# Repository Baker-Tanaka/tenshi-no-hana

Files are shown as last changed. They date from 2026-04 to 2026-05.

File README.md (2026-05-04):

# Angel's Nose - ROS2 × Baker link. Dev × Rover

> ⚠️ This project is under active development. Features, wiring, and documentation may change.

**A whiskey barrel patrol rover that detects alcohol vapor, environmental conditions, and barrel liquid level.**

## Illustrative Image

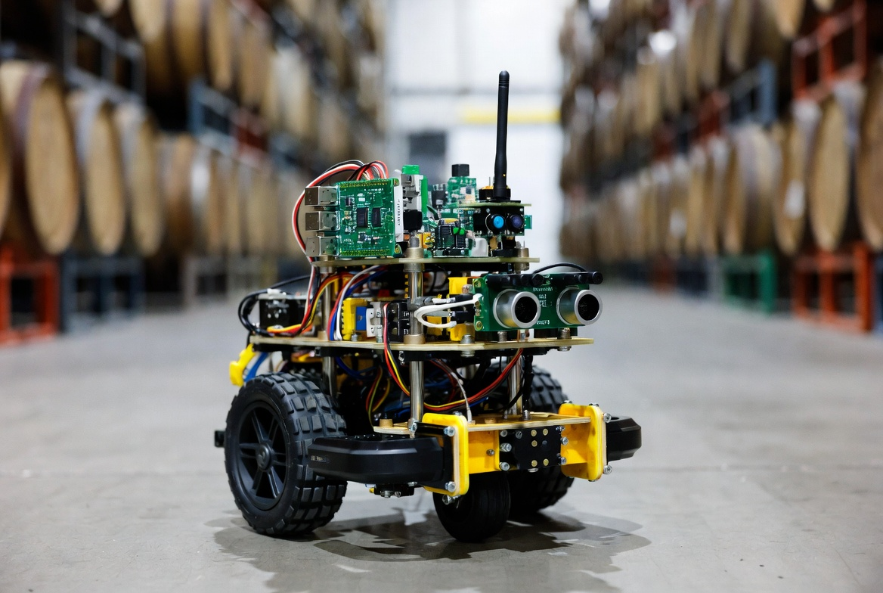
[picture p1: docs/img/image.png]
Project preview


System diagram

> 日本語版はこちら: [README.ja.md](./README.ja.md)

## Overview
Angel's Nose is a compact 2-wheel rover based on the Baker link. Dev(RP2040) board. It patrols distilleries and barrel aging warehouses, detects ethanol vapor, measures temperature, humidity, and pressure, and estimates barrel liquid surface using magnetic sensing.

This project combines:
- **Baker link. Dev (RP2040)**
- **XIAO-ESP32-C3 as a Wi-Fi ESP-hosted MCU**
- **Embassy-rs no_std async runtime**
- **micro_xrce_dds_rs** with a **micro-ROS Agent** bridge

## Key features
- Ethanol vapor detection as a proxy for the barrel's "angel's share"
- Environmental sensing with temperature, humidity, and pressure
- Non-contact barrel liquid level sensing using a floating magnet and magnetic field sensor
- Wi-Fi communication via XIAO-ESP32-C3
- Low-cost and lightweight no_std embedded design

## Hardware bill of materials
Estimated Japan-focused pricing as of April 2026.

| Part | Example | Approx. Price | Link | Notes |
| --- | --- | --- | --- | --- |
| 2WD robot chassis  | FT-DC-002 / 2WD Mini Smart Robot Mobile Platform Kit | ¥1,900 | [Akizuki](https://akizukidenshi.com/catalog/g/g113651/) | Includes motors; encoder-free version available |
| Baker link. Dev | - | ¥1,980 | [Switch Science](https://www.switch-science.com/products/10044) | Native Embassy-rs / Rust no_std support |
| Motor driver | DRV8835 dual motor driver | ¥400–1,395 | [Akizuki](https://akizukidenshi.com/catalog/g/g109848/) | Ideal for direct PWM motor control |
| Ethanol sensor | MQ-3B or MQ-3 module | ¥450 | [Akizuki](https://akizukidenshi.com/catalog/g/g116269/) | Main sensor for vapor detection; heater requires 5 V / 150 mA |
| Voltage divider | 10 kΩ + 15 kΩ resistors | < ¥10 | — | Required: scales MQ-3B AOUT (0–5 V) to 0–3 V for RP2040 ADC |
| Environment sensor | BME280 module (AE-BME280) | ¥1,650 | [Switch Science](https://www.switch-science.com/products/2236)  | Required for evaporation compensation |
| Optional IMU | 6-axis IMU module | ¥990 | [Switch Science](https://www.switch-science.com/products/8695)  | Useful for odometry and attitude estimation |
| Ultrasonic sensor  | - | ¥300 | [Switch Science](https://www.switch-science.com/products/8224/) | For obstacle avoidance |

```
GPIOs: CLK:6 MOSI:7 MISO:5 CS:10 HS:3 DR:4
```

## Wiring



> **MQ-3B wiring note**: The heater (VCC pin) requires a **5 V / 150 mA** external supply.
> AOUT can swing up to VCC (~5 V), which would damage the RP2040's 3.3 V ADC input.
> Add a **10 kΩ + 15 kΩ voltage divider** between AOUT and GP26 as shown in the schematic above.
> Allow ~2 minutes warm-up after power-on; the firmware suppresses publishing during this period.

## Wireless stack
- Uses **XIAO-ESP32-C3** with ESP-hosted MCU firmware
- Uses the `external/embassy` submodule and `embassy-net-esp-hosted` from the `upstream-esp-hosted-mcu` fork

## Software stack
- `micro_xrce_dds_rs` with micro-ROS Agent TCP transport
- Custom message support for `angel_nose_msgs` (ethanol level, liquid height, environment data)

## How it works
1. Position the rover at a fixed distance from the barrel. ArUco or AprilTag tracking is recommended.
2. Measure barrel liquid level with a floating cork and neodymium magnet using magnetic field sensing.
3. Use the MQ-3 sensor to "sniff" ambient ethanol vapor.

## Future work
- Autonomous mapping and multi-barrel patrol
- Estimating evaporation volume from liquid level data
- Web dashboard for distillery monitoring
- Full Rust no_std implementation across the stack

## ESP32-Hosted (ESP32-C3) pin mapping
Pin assignments are extracted from `sdkconfig`.

> Reference: [Seeed Studio XIAO ESP32C3 Getting Started](https://wiki.seeedstudio.com/XIAO_ESP32_C3_Getting_Started/)

### XIAO ESP32C3 GPIO ↔ physical pin mapping

| XIAO pin | GPIO | Default function | Notes |
| --- | --- | --- | --- |
| D0 | GPIO2  | ADC | ⚠️ Strapping pin |
| D1 | GPIO3  | ADC | |
| D2 | GPIO4  | ADC | MTMS (JTAG) |
| D3 | GPIO5  | ADC | MTDI (JTAG) |
| D4 | GPIO6  | SDA (I2C) | FSPICLK, MTCK (JTAG) |
| D5 | GPIO7  | SCL (I2C) | FSPID, MTDO (JTAG) |
| D6 | GPIO21 | UART TX | |
| D7 | GPIO20 | UART RX | |
| D8 | GPIO8  | SPI SCK | ⚠️ Strapping pin |
| D9 | GPIO9  | SPI MISO | ⚠️ Strapping pin / BOOT button |
| D10 | GPIO10 | SPI MOSI | FSPICS0 |

### Recommended esp-hosted slave wiring

> Avoid all strapping pins (GPIO2/8/9) for stable operation.

| Signal | GPIO | XIAO pin | Purpose |
| --- | --- | --- | --- |
| SPI MOSI | GPIO7  | D5 | Required |
| SPI MISO | GPIO5  | D3 | Required |
| SPI CLK | GPIO6  | D4 | Required |
| SPI CS | GPIO10 | D10 | Required |
| Handshake  | GPIO3  | D1 | Timing sync |
| Data Ready | GPIO4  | D2 | Data arrival notification |
| Reset | GPIO21 | D6 | Recommended |

#### Changes from previous wiring

| Signal | Old GPIO | New GPIO | Reason |
| --- | --- | --- | --- |
| SPI MISO | GPIO2 (D0) | GPIO5 (D3)  | Avoid strapping pin and boot instability |
| Reset | none | GPIO21 (D6) | Add host reset control |

#### Spare pins

| XIAO pin | GPIO | Notes |
| --- | --- | --- |
| D0 | GPIO2  | Spare, but avoid strapping pin |
| D7 | GPIO20 | Spare UART RX for debugging |
| D8 | GPIO8  | Spare, but avoid strapping pin |
| D9 | GPIO9  | Spare, but avoid BOOT button pin |

### ESP-IDF menuconfig setup

```powershell
idf.py menuconfig
```

Navigate to **Example Configuration → Bus Config → SPI Full-Duplex Configuration** and set:

| Option | Value |
| --- | ----- |
| SPI MOSI (GPIO) | 7 |
| SPI MISO (GPIO) | 5 |
| SPI CLK (GPIO) | 6 |
| SPI CS (GPIO) | 10 |
| Handshake (GPIO)  | 3 |
| Data Ready (GPIO) | 4 |
| Reset pin (GPIO)  | 21 |

Save and rebuild.

```bash
# Create esp-hosted-mcu slave sample (ESP-IDF v5.3+ assumed)
idf.py create-project-from-example "espressif/esp_hosted:slave"
cd slave
idf.py set-target esp32c3
idf.py menuconfig
# Set SPI Full-Duplex Configuration:
#   MISO=5, MOSI=7, CLK=6, CS=10, HS=3, DR=4
#   Reset GPIO=21
idf.py build flash
```

## Submodule setup

RP2040-side dependencies are managed via git submodules:

```bash
git submodule update --init --recursive external/embassy external/micro_xrce_dds_rs
```

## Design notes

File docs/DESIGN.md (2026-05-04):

# 天使の鼻 — 設計書 (DESIGN.md)

> **プロジェクト名**: 天使の鼻 (Angel's Nose)
> **最終更新**: 2026-04-19

---

## 1. プロジェクト概要

ウィスキー蒸留所・熟成庫内を自律巡回する 2WD ローバー。
空気中のエタノール蒸気（天使の分け前）、温湿度・気圧、樽内液面を計測し、
ROS2 経由でリアルタイム監視する。

**コアスタック**: Baker link. Dev (RP2040) + Embassy-rs (Rust no\_std) + micro_xrce_dds_rs / micro-ROS Agent

---

## 2. システムアーキテクチャ

```text
┌───────────────────────────────────────────────────────────┐
│                Baker link. Dev (RP2040)                    │
│                   SPI Master                              │
│                                                           │
│  ┌──────────┐  ┌──────────┐  ┌──────────┐  ┌──────────┐ │
│  │ MQ-3     │  │ BME280   │  │ DRV8835  │  │ HC-SR04  │ │
│  │ (ADC)    │  │ (I2C)    │  │ (PWM)    │  │ (GPIO)   │ │
│  │ GP26     │  │ GP4/GP5  │  │ GP10-11  │  │ GP2/GP3  │ │
│  └──────────┘  └──────────┘  └──────────┘  └──────────┘ │
│                                                           │
│  ┌──────────────────────────────────────────────────────┐ │
│  │  SPI0 (GP16-19) + Control (GP13-15)                  │ │
│  │  embassy-net-esp-hosted                               │ │
│  └──────────────────┬───────────────────────────────────┘ │
└─────────────────────┼─────────────────────────────────────┘
                      │ SPI Full-Duplex
                      │ + Handshake / Data Ready / Reset
┌─────────────────────┼─────────────────────────────────────┐
│  XIAO ESP32-C3      │                                     │
│  esp-hosted-mcu     ▼                                     │
│  (SPI Slave)  ── WiFi ──► AP                              │
└───────────────────────────────────────────────────────────┘
                      │
                      │ TCP/IP (WiFi)
                      ▼
┌───────────────────────────────────────────────────────────┐
│  Host PC / Docker                                         │
│                                                           │
│  ┌──────────────┐  ┌────────────────┐  ┌──────────────┐  │
│  │ micro-ROS    │  │ ROS2 Node      │  │ Web          │  │
│  │ Agent :8888  │  │ rmw_fastrtps_cpp │  │ Dashboard    │  │
│  └──────────────┘  └────────────────┘  └──────────────┘  │
└───────────────────────────────────────────────────────────┘
```

---

## 3. ソフトウェアレイヤー

```text
┌─────────────────────────────────────────────────────┐
│  Application (examples/wifi_microros_sensors.rs)    │
│  Publisher<StringMsg> / Subscription<StringMsg>     │
├─────────────────────────────────────────────────────┤
│  micro_xrce_dds_rs   (external/micro_xrce_dds_rs)   │
│  ┌─────────────────────────────────────────────┐    │
│  │  sdk/  — NodeBuilder, Node, spin()          │    │
│  │  ros2/ — TopicKeyExpr, Publisher, Sub, QoS  │    │
│  │  session/ — Session, Reconnect              │    │
│  │  transport/ — XRCE-DDS, TCP, fragmentation   │    │
│  │  cdr/  — CDR LE serialization               │    │
│  └─────────────────────────────────────────────┘    │
├─────────────────────────────────────────────────────┤
│  embassy-net  (TCP/IP stack)                        │
│  └── TcpSocket  — Read + Write → NodeBuilder       │
├─────────────────────────────────────────────────────┤
│  embassy-net-esp-hosted  (WiFi over SPI)            │
│  └── EspHosted → NetDevice                          │
├─────────────────────────────────────────────────────┤
│  embassy-rp  (RP2040 HAL)                           │
│  └── SPI0 (async) + GPIO (Handshake/DR/Reset)       │
├─────────────────────────────────────────────────────┤
│  Hardware: Baker link. Dev ↔ XIAO ESP32-C3 (SPI)    │
└─────────────────────────────────────────────────────┘
```

---

## 4. ハードウェア構成

### 4.1 BOM 要約

| 部品 | 品番 | 価格目安 | 役割 |
| --- | --- | --- | --- |
| 2WD シャーシ | FT-DC-002 | ¥1,900 | 車体 |
| Baker link. Dev | RP2040 | ¥1,980 | メインMCU |
| XIAO ESP32-C3 | Seeed Studio | ¥800 | WiFi コプロセッサ (esp-hosted) |
| DRV8835 | デュアルモータードライバ | ¥400 | モーター制御 |
| MQ-3B | エタノールセンサー | ¥450 | 天使の分け前検知 |
| BME280 | AE-BME280 モジュール | ¥1,080 | 温湿度・気圧 |
| HC-SR04 | 超音波センサー | ¥300 | 障害物回避 |

### 4.2 RP2040 (Baker link. Dev) ↔ XIAO ESP32-C3 SPI 接続

> WIZ630io と同一 SPI0 バスレイアウト (GP14-19) を再利用

| RP2040 GPIO | ESP32-C3 GPIO | XIAO Pin | 信号名 | 用途 |
| --- | --- | --- | --- | --- |
| GP16 (SPI0 RX)  | GPIO5 | D3 | SPI MISO | データ入力 |
| GP17 (GPIO out) | GPIO10 | D10 | SPI CS | チップセレクト |
| GP18 (SPI0 SCK) | GPIO6 | D4 | SPI CLK | クロック |
| GP19 (SPI0 TX)  | GPIO7 | D5 | SPI MOSI | データ出力 |
| GP15 (GPIO in)  | GPIO3 | D1 | Handshake  | タイミング同期 |
| GP13 (GPIO in)  | GPIO4 | D2 | Data Ready | データ到着通知 |
| GP14 (GPIO out) | GPIO21 | D6 | Reset | リセット制御 |
| 3V3 OUT | 3V3 | — | 電源 | 3.3V 給電 |
| GND | GND | — | GND | グランド |

### 4.3 RP2040 その他ピンアサイン

| RP2040 GPIO | 機能 | 接続先 |
| --- | --- | --- |
| GP4 (I2C0 SDA) | I2C データ | BME280 SDA |
| GP5 (I2C0 SCL) | I2C クロック | BME280 SCL |
| GP26 (ADC0) | ADC 入力 | MQ-3B アナログ出力 |
| GP10 | PWM (左モーター) | DRV8835 AIN1 |
| GP11 | PWM (右モーター) | DRV8835 BIN1 |
| GP2 | GPIO (Trigger) | HC-SR04 Trig |
| GP3 | GPIO (Echo) | HC-SR04 Echo |
| GP20 | LED (赤) | ステータス LED |
| GP21 | LED (橙) | ステータス LED |
| GP22 | LED (緑) | ステータス LED |

### 4.4 注意事項

1. **ESP32-C3 の I2C ピン (D4/D5) は SPI で占有** — I2C センサーはすべて RP2040 側に接続
2. **ESP32-C3 の JTAG デバッグ不可** — GPIO4〜7 が SPI + 信号線で使用済み。USB シリアルでデバッグ
3. **GPIO9 (BOOT ボタン) は Data Ready に使用不可** — GPIO4 (D2) に変更済み
4. **ストラッピングピン (GPIO2/8/9) は未使用**

---

## 5. ESP32-C3 esp-hosted-mcu スレーブ準備

ESP32-C3 は **esp-hosted-mcu** ファームウェアを書き込み、SPI スレーブとして動作させる。
RP2040 から `embassy-net-esp-hosted` 経由で WiFi 接続を利用する。

### 5.1 ファームウェアビルド手順

```sh
# esp-hosted-mcu リポジトリをクローン
git clone --recursive https://github.com/espressif/esp-hosted-mcu.git
cd esp-hosted-mcu

# ESP-IDF 環境セットアップ
. ./esp-idf/export.sh

# ターゲットを ESP32-C3 に設定
idf.py set-target esp32c3

# ピン設定のカスタマイズ
idf.py menuconfig
```

### 5.2 menuconfig 設定

**Example Configuration → Bus Config → SPI Full-Duplex Configuration:**

| 設定項目 | 値 |
| --- | --- |
| SPI MOSI (GPIO) | **7**  |
| SPI MISO (GPIO) | **5**  |
| SPI CLK (GPIO) | **6**  |
| SPI CS (GPIO) | **10** |
| Handshake (GPIO)  | **3**  |
| Data Ready (GPIO) | **4**  |
| Reset pin (GPIO)  | **21** |

### 5.3 ビルド・フラッシュ

```sh
# ビルド
idf.py build

# XIAO ESP32-C3 を BOOT モードで USB 接続
# (BOOT ボタンを押しながら USB 接続、または BOOT + RESET)
idf.py -p /dev/ttyACM0 flash

# ログ確認 (オプション)
idf.py -p /dev/ttyACM0 monitor
```

フラッシュ後、ESP32-C3 は SPI スレーブとして起動し、RP2040 からの SPI コマンドを待機する。

---

## 6. 開発ロードマップ

### Phase 1: WiFi 通信（最優先）

ESP32-C3 (esp-hosted) 経由で micro-ROS Agent に TCP 接続し、ROS2 トピックを pub/sub する。

| ステップ | 内容 | 成果物 |
| --- | --- | --- |
| 1-1 | ESP32-C3 に esp-hosted-mcu ファームウェア書き込み | ESP32-C3 SPI スレーブ起動 |
| 1-2 | Cargo.toml に WiFi 依存追加 | `wifi` feature flag |
| 1-3 | WiFi 通信サンプル作成 | `examples/wifi_microros_sensors.rs` |
| 1-4 | 動作確認 (Docker + verify_sub.py) | `/chatter` メッセージ受信 |

**検証基準**:
- `cargo build --no-default-features --features wifi --example wifi_microros_sensors` 成功
- RTT ログ: DHCP 取得 → TCP 接続 → micro-ROS XRCE-DDS セッション成功
- `verify_sub.py` で `/chatter` メッセージ受信

### Phase 2: センサー統合

BME280 (I2C) と MQ-3B (ADC) のセンサーデータを取得し、ROS2 トピックとしてパブリッシュする。

| ステップ | 内容 | 成果物 | 状態 |
| --- | --- | --- | ---- |
| 2-1 | BME280 I2C ドライバ統合 | `bme280` crate (sync/blocking I2C)  | ✅ |
| 2-2 | MQ-3 ADC 読み取り | embassy-rp ADC (GP26) | ✅ |
| 2-3 | スタンドアロンセンサー読み取り | `examples/sensor_read.rs` | ✅ |
| 2-4 | センサーデータ ROS2 パブリッシュ | `examples/wifi_microros_sensors.rs` | ✅ |

**ROS2 トピック**:

| トピック | 型 | 内容 |
| --- | --- | --- |
| `/angel_nose/temperature` | `std_msgs/Float32` | BME280 温度 [°C]  |
| `/angel_nose/humidity` | `std_msgs/Float32` | BME280 湿度 [%] |
| `/angel_nose/pressure` | `std_msgs/Float32` | BME280 気圧 [hPa] |
| `/angel_nose/ethanol` | `std_msgs/Float32` | MQ-3B 電圧 [V] |

**ビルドコマンド**:
```sh
# センサー単体テスト
cargo build --no-default-features --features sensor --example sensor_read

# WiFi + センサー + micro-ROS パブリッシュ
cargo build --no-default-features --features wifi,sensor --example wifi_microros_sensors
```

**検証基準**:
- `cargo check --features sensor --example sensor_read` 成功
- `cargo check --features wifi,sensor --example wifi_microros_sensors` 成功
- RTT ログ: BME280 温湿度気圧 + MQ-3B ADC 値の周期的出力
- ROS2 側: `ros2 topic echo /angel_nose/temperature std_msgs/msg/Float32` でデータ受信

### Phase 3: モーター制御

| ステップ | 内容 | 成果物 |
| --- | --- | --- |
| 3-1 | DRV8835 PWM 制御 | 2WD 前後進・旋回 |
| 3-2 | `/cmd_vel` サブスクライブ | Twist → モーター PWM 変換 |

### Phase 4: 障害物回避・ナビゲーション

| ステップ | 内容 | 成果物 |
| --- | --- | --- |
| 4-1 | HC-SR04 超音波測距 | 前方障害物距離 |
| 4-2 | IMU (6 軸) odom 計算 | 姿勢推定 |
| 4-3 | 簡易障害物回避ロジック | 自律走行 |

### Phase 5: 統合・自律巡回

| ステップ | 内容 | 成果物 |
| --- | --- | --- |
| 5-1 | 複数樽巡回マッピング | ArUco/AprilTag 位置推定 |
| 5-2 | 液面磁界測定 | 浮遊ネオジム磁石 + ホールセンサー |
| 5-3 | 天使の分け前蒸発量推定 | エタノール + 液面データ統合 |
| 5-4 | Web ダッシュボード | ROS2 → WebSocket → ブラウザ |

---

## 7. WiFi 通信の実装パターン

`examples/wifi_microros_sensors.rs` をテンプレートとし、`embassy-net-wiznet` を `embassy-net-esp-hosted` に置換する。

### 7.1 タスク構成

```text
main()
  ├── esp_hosted_task  — SPI 通信ドライバループ
  ├── net_task         — embassy-net パケット I/O ループ
  ├── microros_task    — DHCP → TCP → XRCE-DDS / micro-ROS → Node::spin()
  └── app_task         — Publisher.send() / Subscription.try_recv()
```

### 7.2 トランスポート抽象化

micro_xrce_dds_rs の `XrceSession::connect()` は `T: Read + Write` を受け取る。
TCP ソケットをそのまま渡せるため、WiFi/Ethernet の違いはネットワークデバイス層のみ。

```rust
let mut socket = TcpSocket::new(stack, &mut rx, &mut tx);
socket.connect(agent_endpoint).await?;
let session = XrceSession::connect(socket, SESSION_ID, CLIENT_KEY).await?;
```

---

## 8. ビルド・デプロイ

### 8.1 開発環境

- **Dev Container**: Rust 1.94.1 + thumbv6m-none-eabi
- **デバッガ**: probe-rs (Baker link. Dev 内蔵 CMSIS-DAP)
- **ROS2**: Docker (micro-ROS Agent)

### 8.2 ビルドコマンド

```sh
# 通常ビルド (HAL + defmt)
cargo build --release

# Embassy サンプル
cargo build --no-default-features --features embassy --example embassy_blinky

# WiFi サンプル (Phase 1)
cargo build --no-default-features --features wifi --example wifi_microros_sensors

# 書き込み (probe-rs)
cargo run --release

# UF2 変換 (USB ブートローダ書き込み用)
elf2uf2-rs target/thumbv6m-none-eabi/release/tenshi-no-hana target/tenshi-no-hana.uf2
```

### 8.3 Docker (micro-ROS Agent)

```sh
cd <project_root>
docker compose up -d

# 動作確認
python3 verify_sub.py

# または ROS2 CLI
ros2 topic echo /chatter std_msgs/msg/String
```

---

## 9. 関連リンク

- [Baker link. Dev](https://www.baker-link.com/)
- [embassy-net-esp-hosted](https://github.com/embassy-rs/embassy/tree/embassy-net-esp-hosted-v0.3.0/embassy-net-esp-hosted)
- [esp-hosted-mcu](https://github.com/espressif/esp-hosted-mcu)
- [Seeed Studio XIAO ESP32C3](https://wiki.seeedstudio.com/XIAO_ESP32C3_Getting_Started/)

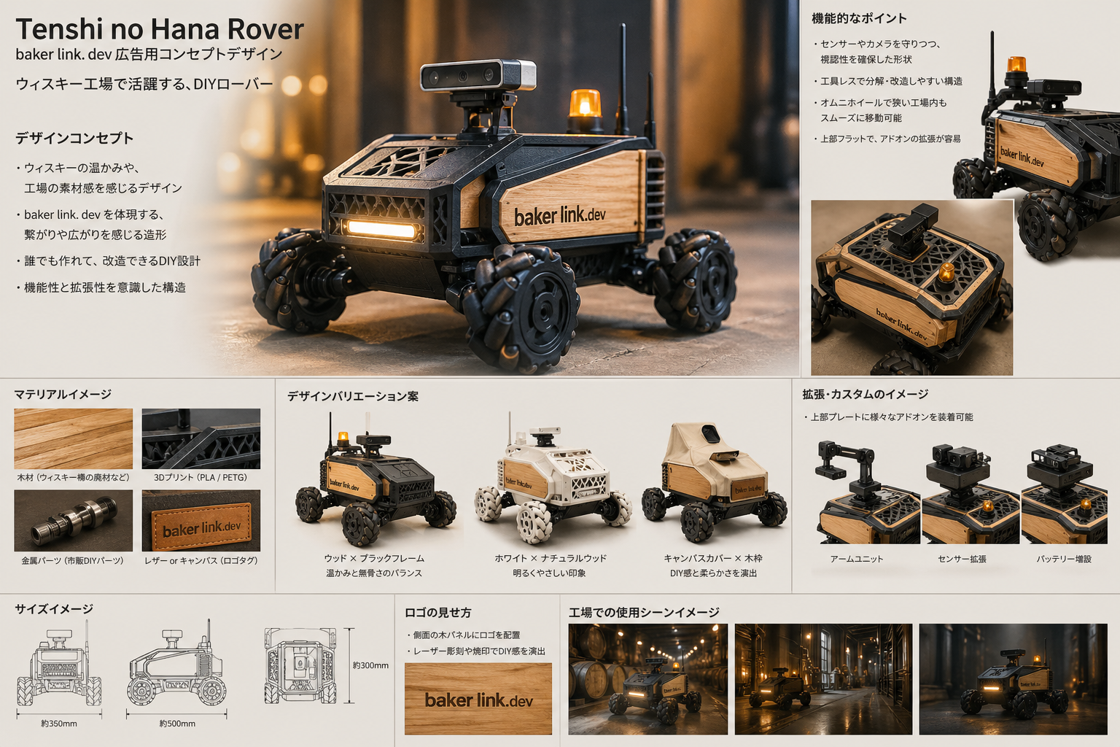
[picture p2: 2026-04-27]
docs/img/tenshinohana_concept.png

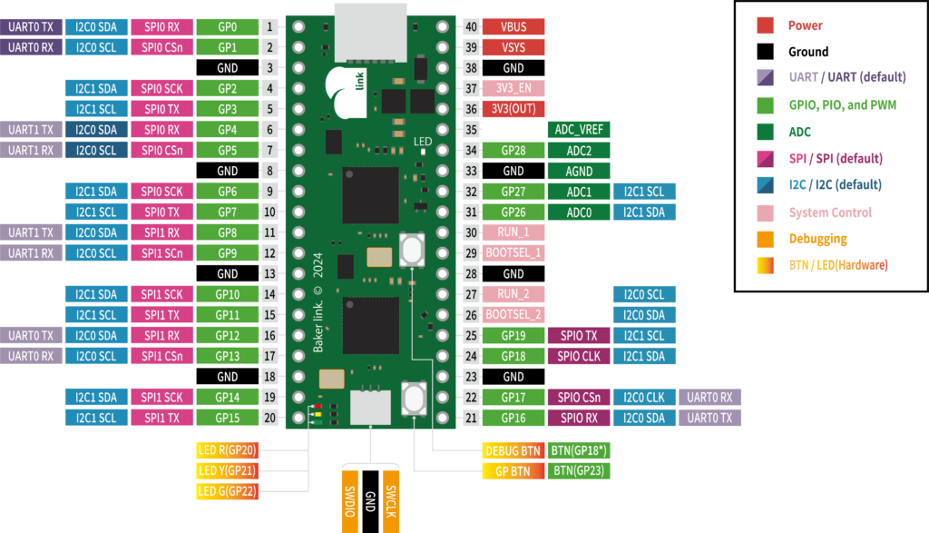
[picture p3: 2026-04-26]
docs/schematics/bld_image.png

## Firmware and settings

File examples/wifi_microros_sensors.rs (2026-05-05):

// wifi_microros_sensors.rs — RP2040 → WiFi → micro-ROS Agent → ROS2 sensor topics.
//
// Published topics:
//   /angel_nose/temperature  std_msgs/Float32   BME280 [°C]
//   /angel_nose/humidity     std_msgs/Float32   BME280 [%]
//   /angel_nose/pressure     std_msgs/Float32   BME280 [hPa]
//   /angel_nose/ethanol      std_msgs/Float32   MQ-3B AOUT [V]
//   /angel_nose/range        sensor_msgs/Range  HC-SR04 [m]
//   /angel_nose/imu          sensor_msgs/Imu    ICM-20602 6-axis
//
// Architecture (v0.2):
//   main()       — hardware init, WiFi, TCP, Runtime::start, spawn tasks
//   xrce_exec    — Executor task (sole TCP socket owner)
//   sensor_node  — reads all sensors AND publishes directly (no inter-task channels)
//
// Build:
//   cargo build --release --no-default-features --features wifi,sensor --example wifi_microros_sensors
#![no_std]
#![no_main]

#[path = "../src/wifi_config.rs"]
mod wifi_config;

use bme280::i2c::BME280;
use core::cell::RefCell;
use cortex_m_rt::exception;
use defmt::*;
use defmt_rtt as _;
use embassy_executor::Spawner;
use embassy_net::tcp::TcpSocket;
use embassy_net::{DhcpConfig, Runner as NetRunner, Stack, StackResources};
use embassy_net_esp_hosted_mcu::{
    self, BufferType, EspConfig, NetDriver, Runner as EspRunner, SpiInterface, State,
    MAX_SPI_BUFFER_SIZE,
};
use embassy_rp::adc::{
    Adc, Channel as AdcChannel, Config as AdcConfig, InterruptHandler as AdcIrqHandler,
};
use embassy_rp::gpio::{Input, Level, Output, Pull};
use embassy_rp::i2c::{Blocking as I2cBlocking, Config as I2cConfig, I2c};
use embassy_rp::spi::{Async as SpiAsync, Config as SpiConfig, Phase, Polarity, Spi};
use embassy_rp::{bind_interrupts, dma, peripherals::*};
use embassy_time::{with_timeout, Delay, Duration, Instant, Timer};
use embedded_hal::i2c::I2c as I2cTrait;
use embedded_hal_bus::i2c::RefCellDevice;
use embedded_hal_bus::spi::ExclusiveDevice;
use micro_xrce_dds_rs::{client_key, msg, Context, Executor, Runtime, RuntimeConfig};
use panic_probe as _;
use static_cell::StaticCell;
use wifi_config::AppConfig;

#[exception]
unsafe fn HardFault(_ef: &cortex_m_rt::ExceptionFrame) -> ! {
    defmt::panic!("HardFault: possible stack overflow or bus fault");
}

bind_interrupts!(struct Irqs {
    DMA_IRQ_0    => dma::InterruptHandler<DMA_CH0>, dma::InterruptHandler<DMA_CH1>;
    ADC_IRQ_FIFO => AdcIrqHandler;
});

const SAMPLE_PERIOD_MS: u64 = 1_000;
const MQ3B_WARMUP_SAMPLES: u32 = (6_000 / SAMPLE_PERIOD_MS) as u32;

type MySpi = Spi<'static, SPI0, SpiAsync>;
type MySpiDevice = ExclusiveDevice<MySpi, Output<'static>, Delay>;
type MySpiIface = SpiInterface<MySpiDevice, Input<'static>>;
type MyEspRunner = EspRunner<'static, MySpiIface, Output<'static>>;
type MyI2cBus = RefCell<I2c<'static, I2C0, I2cBlocking>>;
type MyI2cDev = RefCellDevice<'static, I2c<'static, I2C0, I2cBlocking>>;
type MyBme280 = BME280<MyI2cDev>;
type MyExecutor = Executor<TcpSocket<'static>>;

static ESP_STATE: StaticCell<State> = StaticCell::new();
static STACK_RESOURCES: StaticCell<StackResources<4>> = StaticCell::new();
static I2C_BUS: StaticCell<MyI2cBus> = StaticCell::new();
static RUNTIME: Runtime = Runtime::new();

#[embassy_executor::main]
async fn main(spawner: Spawner) {
    let p = embassy_rp::init(Default::default());
    Timer::after(Duration::from_millis(500)).await;
    info!("[main] start");

    // SPI0 → ESP32-C3 (Mode 3)
    let mut spi_cfg = SpiConfig::default();
    spi_cfg.frequency = 10_000_000;
    spi_cfg.polarity = Polarity::IdleHigh;
    spi_cfg.phase = Phase::CaptureOnSecondTransition;
    let spi = Spi::new(
        p.SPI0, p.PIN_18, p.PIN_19, p.PIN_16, p.DMA_CH0, p.DMA_CH1, Irqs, spi_cfg,
    );
    let cs = Output::new(p.PIN_17, Level::High);
    let handshake = Input::new(p.PIN_15, Pull::Down);
    let data_ready = Input::new(p.PIN_13, Pull::Down);
    let reset = Output::new(p.PIN_14, Level::Low);

    let spi_dev = ExclusiveDevice::new(spi, cs, Delay).unwrap();
    let spi_iface = SpiInterface::new(spi_dev, handshake, data_ready);
    let esp_state = ESP_STATE.init(State::new());
    let (net_device, mut control, esp_runner) =
        embassy_net_esp_hosted_mcu::new(esp_state, spi_iface, reset, None).await;
    spawner.spawn(esp_hosted_task(esp_runner).unwrap());

    let cfg = AppConfig::new();
    info!("[wifi] connecting to \"{}\"...", cfg.wifi_ssid);
    defmt::unwrap!(
        control
            .init(EspConfig {
                static_rx_buf_num: 10,
                dynamic_rx_buf_num: 32,
                tx_buf_type: BufferType::Dynamic,
                static_tx_buf_num: 0,
                dynamic_tx_buf_num: 32,
                rx_mgmt_buf_type: BufferType::Dynamic,
                rx_mgmt_buf_num: 20,
            })
            .await
    );
    let connected = defmt::unwrap!(control.connect(cfg.wifi_ssid, cfg.wifi_password).await);
    defmt::assert!(connected, "WiFi association failed");
    info!("[wifi] connected");

    let (stack, net_runner) = embassy_net::new(
        net_device,
        embassy_net::Config::dhcpv4(DhcpConfig::default()),
        STACK_RESOURCES.init(StackResources::new()),
        0x1234_5678_9abc_def0u64,
    );

    // I2C0: BME280 @ 0x76, ICM-20602 @ 0x68
    let raw_i2c = I2c::new_blocking(p.I2C0, p.PIN_5, p.PIN_4, I2cConfig::default());
    let i2c_bus = I2C_BUS.init(RefCell::new(raw_i2c));

    let bme_dev = RefCellDevice::new(i2c_bus);
    let mut bme280: MyBme280 = BME280::new_primary(bme_dev);
    match bme280.init(&mut Delay) {
        Ok(()) => info!("[bme280] initialized"),
        Err(_) => error!("[bme280] init failed — check wiring"),
    }
    {
        let mut imu_tmp = RefCellDevice::new(i2c_bus);
        match icm20602_init(&mut imu_tmp).await {
            Ok(()) => info!("[imu] ICM-20602 ready"),
            Err(()) => error!("[imu] ICM-20602 init failed"),
        }
    }
    let imu_dev = RefCellDevice::new(i2c_bus);

    let adc = Adc::new(p.ADC, Irqs, AdcConfig::default());
    let mq3_ch = AdcChannel::new_pin(p.PIN_26, Pull::None);
    let trig = Output::new(p.PIN_2, Level::Low);
    let echo = Input::new(p.PIN_3, Pull::None);

    spawner.spawn(net_task(net_runner).unwrap());

    // Wait for DHCP.
    while stack.config_v4().is_none() {
        Timer::after(Duration::from_millis(500)).await;
    }
    info!("[microros] DHCP OK");

    static TCP_RX: StaticCell<[u8; 4096]> = StaticCell::new();
    static TCP_TX: StaticCell<[u8; 4096]> = StaticCell::new();
    let tcp_rx = TCP_RX.init([0u8; 4096]);
    let tcp_tx = TCP_TX.init([0u8; 4096]);

    let agent_ep = cfg.agent_endpoint();
    let mut socket = TcpSocket::new(stack, tcp_rx, tcp_tx);
    socket.set_timeout(Some(Duration::from_secs(30)));
    if with_timeout(Duration::from_secs(10), socket.connect(agent_ep))
        .await
        .map(|r| r.is_ok())
        .unwrap_or(false)
    {
        info!("[microros] TCP connected");
    } else {
        defmt::panic!("[microros] TCP connect timeout");
    }

    let (ctx, exec) = defmt::unwrap!(
        RUNTIME
            .start(socket, RuntimeConfig::new(0x81, client_key!()))
            .await
    );
    info!("[microros] runtime started");

    spawner.spawn(xrce_exec(exec).unwrap());
    spawner
        .spawn(sensor_node(ctx, bme280, adc, mq3_ch, trig, echo, imu_dev))
        .unwrap();
}

#[embassy_executor::task]
async fn esp_hosted_task(runner: MyEspRunner) {
    static TX_BUF: StaticCell<[u8; MAX_SPI_BUFFER_SIZE]> = StaticCell::new();
    static RX_BUF: StaticCell<[u8; MAX_SPI_BUFFER_SIZE]> = StaticCell::new();
    runner
        .run(
            TX_BUF.init([0u8; MAX_SPI_BUFFER_SIZE]),
            RX_BUF.init([0u8; MAX_SPI_BUFFER_SIZE]),
        )
        .await
}

#[embassy_executor::task]
async fn net_task(mut runner: NetRunner<'static, NetDriver<'static>>) {
    runner.run().await
}

#[embassy_executor::task]
async fn xrce_exec(exec: MyExecutor) -> ! {
    exec.run().await
}

/// Reads all sensors and publishes to micro-ROS — no inter-task channels needed.
#[embassy_executor::task]
async fn sensor_node(
    ctx: Context,
    mut bme280: MyBme280,
    mut adc: Adc<'static, embassy_rp::adc::Async>,
    mut mq3_ch: AdcChannel<'static>,
    mut trig: Output<'static>,
    mut echo: Input<'static>,
    mut imu_dev: MyI2cDev,
) -> ! {
    let node = defmt::unwrap!(ctx.create_node("tenshi_no_hana").await);
    let pub_temp = defmt::unwrap!(
        node.create_publisher::<msg::std_msgs::Float32>("/angel_nose/temperature")
            .await
    );
    let pub_humi = defmt::unwrap!(
        node.create_publisher::<msg::std_msgs::Float32>("/angel_nose/humidity")
            .await
    );
    let pub_pres = defmt::unwrap!(
        node.create_publisher::<msg::std_msgs::Float32>("/angel_nose/pressure")
            .await
    );
    let pub_etoh = defmt::unwrap!(
        node.create_publisher::<msg::std_msgs::Float32>("/angel_nose/ethanol")
            .await
    );
    let pub_range = defmt::unwrap!(
        node.create_publisher::<msg::sensor_msgs::Range>("/angel_nose/range")
            .await
    );
    let pub_imu = defmt::unwrap!(
        node.create_publisher::<msg::sensor_msgs::Imu>("/angel_nose/imu")
            .await
    );
    info!("[sensor_node] all publishers ready");

    let mut count: u32 = 0;
    loop {
        count += 1;

        if let Ok(m) = bme280.measure(&mut Delay) {
            info!(
                "[sensor] #{}: T={} H={} P={}",
                count,
                m.temperature,
                m.humidity,
                m.pressure / 100.0
            );
            pub_temp.publish(&msg::std_msgs::Float32(m.temperature)).await.ok();
            pub_humi.publish(&msg::std_msgs::Float32(m.humidity)).await.ok();
            pub_pres.publish(&msg::std_msgs::Float32(m.pressure / 100.0)).await.ok();
        }

        if let Ok(raw) = adc.read(&mut mq3_ch).await {
            let v = raw as f32 * 5.5 / 4096.0;
            if count > MQ3B_WARMUP_SAMPLES {
                pub_etoh.publish(&msg::std_msgs::Float32(v)).await.ok();
            }
        }

        if let Some(d) = hcsr04_measure(&mut trig, &mut echo).await {
            let m = msg::sensor_msgs::Range {
                radiation_type: msg::sensor_msgs::RANGE_ULTRASOUND,
                field_of_view: 0.2618,
                min_range: 0.02,
                max_range: 4.0,
                range: d,
                variance: 0.0,
            };
            pub_range.publish(&m).await.ok();
        }

        if let Ok((ax, ay, az, gx, gy, gz)) = icm20602_read(&mut imu_dev) {
            let m = msg::sensor_msgs::Imu {
                orientation: [0.0, 0.0, 0.0, 1.0],
                orientation_covariance: [-1.0, 0.0, 0.0, 0.0, 0.0, 0.0, 0.0, 0.0, 0.0],
                angular_velocity: [gx, gy, gz],
                angular_velocity_covariance: [0.0; 9],
                linear_acceleration: [ax, ay, az],
                linear_acceleration_covariance: [0.0; 9],
            };
            pub_imu.publish(&m).await.ok();
        }

        Timer::after(Duration::from_millis(SAMPLE_PERIOD_MS)).await;
    }
}

async fn hcsr04_measure(trig: &mut Output<'_>, echo: &mut Input<'_>) -> Option<f32> {
    trig.set_high();
    Timer::after(Duration::from_micros(10)).await;
    trig.set_low();
    if with_timeout(Duration::from_millis(30), echo.wait_for_high())
        .await
        .is_err()
    {
        return None;
    }
    let t1 = Instant::now();
    if with_timeout(Duration::from_millis(40), echo.wait_for_low())
        .await
        .is_err()
    {
        return None;
    }
    Some((Instant::now() - t1).as_micros() as f32 / 5800.0)
}

async fn icm20602_init(i2c: &mut impl I2cTrait) -> Result<(), ()> {
    let mut id = [0u8; 1];
    i2c.write_read(0x68, &[0x75], &mut id).map_err(|_| ())?;
    info!("[imu] WHO_AM_I=0x{:02X}", id[0]);
    i2c.write(0x68, &[0x6B, 0x01]).map_err(|_| ())?;
    Timer::after(Duration::from_millis(100)).await;
    Ok(())
}

fn icm20602_read(i2c: &mut impl I2cTrait) -> Result<(f64, f64, f64, f64, f64, f64), ()> {
    let mut buf = [0u8; 14];
    i2c.write_read(0x68, &[0x3B], &mut buf).map_err(|_| ())?;
    const A_SCALE: f64 = 2.0 * 9.80665 / 32768.0;
    const G_SCALE: f64 = 250.0 * core::f64::consts::PI / 180.0 / 32768.0;
    Ok((
        i16::from_be_bytes([buf[0], buf[1]]) as f64 * A_SCALE,
        i16::from_be_bytes([buf[2], buf[3]]) as f64 * A_SCALE,
        i16::from_be_bytes([buf[4], buf[5]]) as f64 * A_SCALE,
        i16::from_be_bytes([buf[8], buf[9]]) as f64 * G_SCALE,
        i16::from_be_bytes([buf[10], buf[11]]) as f64 * G_SCALE,
        i16::from_be_bytes([buf[12], buf[13]]) as f64 * G_SCALE,
    ))
}

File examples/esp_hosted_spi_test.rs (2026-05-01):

// esp_hosted_spi_test.rs — Verify SPI communication with ESP32-C3 (esp-hosted-mcu)
//
// Diagnostic test for SPI bus between Baker link. Dev (RP2040) and XIAO ESP32-C3.
//
// Steps:
//   1. GPIO init
//   2. Pin state diagnostics — manual reset + HS/DR monitoring
//   3. SPI0 + esp-hosted driver start
//   4. Control::init() — IOCTL communication test
//   5. Control::get_status()
//
// Build:
//   cargo build --no-default-features --features wifi --example esp_hosted_spi_test
//
#![no_std]
#![no_main]

use defmt::*;
use defmt_rtt as _;
use embassy_executor::Spawner;
use embassy_net_esp_hosted_mcu::{
    self, BufferType, EspConfig, Runner as EspRunner, SpiInterface, State, MAX_SPI_BUFFER_SIZE,
};
use embassy_rp::gpio::{Input, Level, Output, Pull};
use embassy_rp::spi::{Async, Config as SpiConfig, Phase, Polarity, Spi};
use embassy_rp::{bind_interrupts, dma, peripherals::*};
use embassy_time::{with_timeout, Delay, Duration, Timer};
use embedded_hal_bus::spi::ExclusiveDevice;
use panic_probe as _;
use static_cell::StaticCell;

bind_interrupts!(struct Irqs {
    DMA_IRQ_0 => dma::InterruptHandler<DMA_CH0>, dma::InterruptHandler<DMA_CH1>;
});

type MySpi = Spi<'static, SPI0, Async>;
type MySpiDevice = ExclusiveDevice<MySpi, Output<'static>, Delay>;
type MySpiIface = SpiInterface<MySpiDevice, Input<'static>>;
type MyEspRunner = EspRunner<'static, MySpiIface, Output<'static>>;

static ESP_STATE: StaticCell<State> = StaticCell::new();

#[embassy_executor::main]
async fn main(spawner: Spawner) {
    let p = embassy_rp::init(Default::default());

    defmt::trace!("RTT init");
    Timer::after(Duration::from_millis(500)).await;
    info!("========================================");
    info!("  ESP-Hosted SPI Communication Test");
    info!("  Build: v3 — SPI Mode 3 (CPOL=1/CPHA=1)");
    info!("========================================");

    // ── Step 1: GPIO init ────────────────────────────────────────────────────
    info!("[1/5] GPIO init...");
    info!("  SCK=GP18 MOSI=GP19 MISO=GP16 CS=GP17");
    info!("  HS=GP15  DR=GP13   RST=GP14");

    // HS: Pull::Down (matches ESP32 GPIO_PULLDOWN_ONLY on HS output)
    // DR: Pull::Down (matches ESP32 GPIO_PULLDOWN_ONLY on DR output)
    let handshake = Input::new(p.PIN_15, Pull::Down);
    let data_ready = Input::new(p.PIN_13, Pull::Down);
    let mut reset = Output::new(p.PIN_14, Level::Low); // ESP32 held in reset
    info!("[1/5] OK");

    // ── Step 2: Pin state diagnostics ────────────────────────────────────────
    info!("[2/5] Pin diagnostics (manual reset cycle)...");

    // ESP32 should be in reset (GP14=LOW) — HS/DR should be LOW
    Timer::after_millis(100).await;
    info!(
        "  [reset asserted] HS={} DR={}",
        if handshake.is_high() { "HIGH" } else { "LOW" },
        if data_ready.is_high() { "HIGH" } else { "LOW" },
    );

    // Release reset — ESP32 boots
    reset.set_high();
    info!("  Reset released (GP14=HIGH) — ESP32 booting...");

    // Monitor HS/DR for 3 seconds
    let mut hs_seen_high = false;
    let mut dr_seen_high = false;
    for i in 0..6u8 {
        Timer::after_millis(500).await;
        let hs = handshake.is_high();
        let dr = data_ready.is_high();
        if hs {
            hs_seen_high = true;
        }
        if dr {
            dr_seen_high = true;
        }
        info!(
            "  [t={}ms] HS={} DR={}",
            (i as u16 + 1) * 500,
            if hs { "HIGH" } else { "LOW" },
            if dr { "HIGH" } else { "LOW" },
        );
    }

    if hs_seen_high {
        info!("  >> HS went HIGH — handshake signal OK");
    } else {
        warn!("  >> HS never HIGH — check GP15 <-> ESP32 GPIO3 wiring");
    }
    if dr_seen_high {
        info!("  >> DR went HIGH — data-ready signal OK");
    } else {
        warn!("  >> DR never HIGH — check GP13 <-> ESP32 GPIO4 wiring");
    }

    // Hold ESP32 in reset for the driver to do its own reset cycle
    reset.set_low();
    Timer::after_millis(100).await;
    info!("[2/5] OK — pin diagnostics complete");

    // ── Step 3: SPI0 + driver init ───────────────────────────────────────────
    info!("[3/5] SPI0 init + esp-hosted driver start...");

    let mut spi_cfg = SpiConfig::default();
    spi_cfg.frequency = 10_000_000; // 10 MHz
    spi_cfg.polarity = Polarity::IdleHigh; // CPOL=1
    spi_cfg.phase = Phase::CaptureOnSecondTransition; // CPHA=1  (SPI Mode 3, matches ESP32)

    let spi: MySpi = Spi::new(
        p.SPI0, p.PIN_18, p.PIN_19, p.PIN_16, p.DMA_CH0, p.DMA_CH1, Irqs, spi_cfg,
    );

    let cs = Output::new(p.PIN_17, Level::High);
    let spi_dev: MySpiDevice = ExclusiveDevice::new(spi, cs, Delay).unwrap();
    let spi_iface = SpiInterface::new(spi_dev, handshake, data_ready);

    let esp_state = ESP_STATE.init(State::new());
    let (net_device, mut control, esp_runner) =
        embassy_net_esp_hosted_mcu::new(esp_state, spi_iface, reset, None).await;

    spawner.spawn(esp_hosted_task(esp_runner).unwrap());
    let _ = net_device;

    info!("[3/5] OK — driver started, runner resets ESP32 internally");

    // ── Step 4: Control::init() — IOCTL communication test ──────────────────
    info!("[4/5] control.init() (heartbeat + wifi mode + MAC)...");
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

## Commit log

2026-04-18 feat: initial commit of tenshi-no-hana project with various examples
    - Add Cargo.toml for project configuration and dependencies
    - Implement ADC reading example (adc_read.rs) for reading analog values
    - Create simple LED blinking example (blinky.rs)
    - Add asynchronous LED blinking example using Embassy (embassy_blinky.rs)
    - Implement asynchronous button input handling with Embassy (embassy_button.rs)
    - Create multitasking example using Embassy (embassy_multitask.rs)
    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
2026-04-19 Remove example projects for traffic light button IRQ and UART echo; add WiFi Zenoh chatter and sensor examples; refactor main.rs for multitasking with Embassy; introduce WiFi configuration management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
2026-04-20 Refactor tasks and examples for ESP-Hosted-MCU integration
    - Updated `.vscode/tasks.json` to reflect new example names and added new build tasks for WiFi and sensor examples.
    - Modified `Cargo.toml` to change dependencies for embassy-net-esp-hosted to embassy-net-esp-hosted-mcu and added new examples for WiFi and sensor functionalities.
    - Revised `README.md` to provide updated instructions for using the ESP-Hosted-MCU and added example usage for creating a slave project.
    - Introduced `esp_hosted_spi_test.rs` example to verify SPI communication between RP2040 and ESP32-C3.
    - Updated `wifi_zenoh_chatter.rs` and `wifi_zenoh_sensors.rs` examples to use the new embassy-net-esp-hosted-mcu library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
2026-04-26 feat: update devcontainer and README for new extensions; enhance SVG schematic and clean up example code
2026-05-01 Refactor code structure for improved readability and maintainability
    [tenshi_no_hana.kicad_pcb, tenshi_no_hana.kicad_sch]
2026-05-01 feat: enhance wifi_zenoh_sensors example with additional sensor support and improved publisher registration
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2026-05-01 feat: add sensor sampling interval constant and optimize message sending in wifi_zenoh_sensors example
2026-05-01 fix: update references to "Baker link.dev" to "Baker link. Dev" across documentation and examples
    - Corrected the naming convention in DESIGN.md, SVG diagrams, and example files to ensure consistency in referring to the "Baker link. Dev (RP2040)".
    - Updated the title and descriptions in SVG files to reflect the new naming.
    - Adjusted comments in example Rust files to match the updated naming.
    - Updated submodule reference for zenoh_ros2_nostd.
    [esp_hosted_spi_test.rs, sensor_read.rs]
2026-05-03 Update MQ-3B sensor schematic: clarify voltage divider details and improve labeling
    [tenshi_no_hana.kicad_sch]
2026-05-03 fix: update MQ-3B ethanol voltage calculation and add warm-up period handling
2026-05-04 Refactor WiFi and micro-ROS Agent configuration
    - Removed the `wifi_zenoh_sensors.rs` example file.
    - Deleted the `zenoh_ros2_nostd` external subproject.
    - Added a PowerShell script `setup_portproxy.ps1` to configure port forwarding for micro-ROS Agent in WSL2/Docker.
    - Updated `wifi_config.rs` to reflect changes in configuration structure, replacing Zenoh router settings with micro-ROS Agent settings.
    - Modified `wifi_config.json.example` to use `agent_addr` instead of `router_addr`.
2026-05-04 feat: add microros_subscriber example and improve wifi_microros_sensors
    - Introduced a new example `microros_subscriber.rs` that subscribes to the `/cmd_vel` topic and logs the received messages.
    - Updated `wifi_microros_sensors.rs` to streamline the code, removing unnecessary comments and improving readability.
    - Refactored the way WiFi connection parameters are handled and improved error handling for sensor readings.
    - Simplified the creation of publishers for sensor data in the `microros_task`.
    - Enhanced the parsing of the agent address in `wifi_config.rs` for better clarity and maintainability.
    [microros_subscriber.rs, wifi_microros_sensors.rs]
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2026-05-09 feat: add wifi_microros_rover example with integrated sensor publishers and cmd_vel subscriber
    - Introduced `wifi_microros_rover.rs` to combine sensor data publishing and motor control via ROS2.
    - Implemented differential drive kinematics for motor control based on received Twist messages.
    - Added watchdog functionality to stop motors if no cmd_vel message is received within 500 ms.
    - Integrated BME280 sensor for environmental data (temperature, humidity, pressure).
    - Included MQ-3B sensor for ethanol detection and HC-SR04 for distance measurement.
    - Added IMU support using ICM-20602 for motion sensing.
    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
2026-08-29 Refactor WiFi micro-ROS rover firmware
    - Rearranged module imports in `wifi_microros_rover.rs` for clarity.
    - Added constants for motor duty scaling and odometry publishing period.
    - Implemented shared motion state management using atomic variables.
    - Enhanced motor control logic to limit duty cycle for motor protection.
    - Improved odometry calculations with dead-reckoning and covariance settings.
    - Added helper functions for motion state publishing and reading.
    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
2026-08-29 Refactor motor control and add ICM-20602 IMU support
    - Improved readability of motor control functions in drv8835.rs by formatting conditional statements.
    - Introduced a new module for the ICM-20602 IMU sensor, implementing initialization and data reading functions.
    - Updated main.rs to integrate the ICM-20602 sensor, replacing the previous BME280 and related environmental sensing code.
    - Added an OpenLoopOdometry struct for estimating robot pose based on motor commands, replacing the previous odometry logic.
    - Updated ROS2 topic names to remove the "angel_nose" namespace for cleaner integration.
    - Implemented time synchronization with the micro-ROS agent to improve timestamp accuracy.
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2026-08-31 feat: Update project documentation and launch configurations for improved navigation
    - Refactored CLAUDE.md to streamline hardware design information.
    - Removed obsolete nav2_amcl_params.yaml configuration file.
    - Simplified bringup.launch.py by removing unnecessary localization mode arguments.
    - Updated README files to reflect changes in launch commands and hardware references.
    - Enhanced test coverage for odometry and command velocity functionalities.
    - Added rover_math.rs test file to validate differential drive calculations.
    - Improved WiFi configuration parsing for better error handling.
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2026-10-10 Refactor ROS integration and remove unused components
    - Updated the micro_xrce_dds_rs submodule to the latest commit.
    - Refactored the launch process to utilize embassy_ros for context management and node initialization.
    - Replaced session-based communication with context-based communication in the IMU, motor, odometry, and range nodes.
    - Removed the time_sync module as its functionality was deemed unnecessary.
    - Enhanced error handling and logging for publisher and subscription operations.
    - Updated message publishing to use the new ROS message structure and timestamp handling.
    - Cleaned up unused imports and code comments for better readability.
2026-10-11 Refactor micro_xrce_dds_rs runtime and remove outdated documentation
    - Deleted runtime design document as it is no longer relevant.
    - Removed runtime roadmap document to streamline project management.
    - Cleared settings.json as it contained unnecessary permissions.
    - Eliminated XRCE-DDS protocol documentation due to discrepancies with current implementation.
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
